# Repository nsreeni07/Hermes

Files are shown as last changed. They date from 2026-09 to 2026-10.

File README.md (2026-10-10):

# Hermes
A 1.7m dual-deployment rocket for both L1 and L2 certification flights, with two redundant flight computers each able to trigger deployment independently. The custom Polaris board also logs data and GPS, with LoRa telemetry in progress for live ground tracking.

I made this project as part of my L1 and L2 certifications and to build my knowledge in rocketry and electronics!

Onshape: https://cad.onshape.com/documents/f1774f8f284ac4e0e452cbcf/w/6986ab179f432bdf2c956942/e/921751107e9de1a38870b9fc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









|Category |Name |Price  |Source |Purpose |FIELD6|Quantity|
|---|---|---|---|---|---|---|
|Electronics |JLC PCB |$250.00|JLCPCB | | | |
| |Header Pins |$0.90  |https://tinyurl.com/3wcsp2uy | | |1 |
| |Screw Terminals |$0.00  |Already Have | | |1 |
| |JST Connector |$0.00  |Already Have | | |1 |
| |Eggtimer Quantum|$40.00 |https://eggtimerrocketry.com/home/altimeters-av-bay/ |Dual Depolyement Controller | |1 |
| |30AWG Wire |$7.76  |https://www.aliexpress.com/item/3256808061834409.html |Wire | |1 |
| |24AWG Wire |$3.14  |https://www.aliexpress.us/item/3256806193213283.html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 |Wire | |1 |
| |Ipex to SMA |$1.50  |https://www.aliexpress.us/item/3256804886872801.html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 |Converter | |1 |
| |915mhz Antenna  |$3.79  |https://www.aliexpress.us/item/3256806722102680.html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 |Antenna | |1 |
| |SK6812 Mini |$4.87  |https://www.aliexpress.us/item/3256810305129996.html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 |SMD Led | |1 |
| |Lipo Battery |$11.52 |https://www.aliexpress.us/item/3256805071060352.html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 |Battery for Flight Computers | |2 |
| | | | | | | |
| | | | | | | |
| | | | | | | |
|Category |Name |Price  |Source |Purpose | |Quantity|
|Hardware |4.00in Body Tube|$35.54 |https://locprecision.com/products/cardboard-airframes?variant=39778656157887 |Main Airframe | |2 |
| |Coupler Tube |$8.02  |https://locprecision.com/products/tube-coupler?variant=39778656583871 |Coupler Tube/Avionics Bay | |1 |
| |Engine Block |$6.18  |https://locprecision.com/products/motor-mount-tubing?variant=39778657075391 |Engine Block | |1 |
| |1/4 U-Bolt |$13.29 |https://locprecision.com/products/eye-bolt-set?variant=39778646655167 |U Bolt for Avionics and Nose Cone | |3 |
| |3/8 U-Bolt |$6.00  |https://locprecision.com/products/eye-bolt-set?variant=48207573090537 |U Bolt on Fin Can | |1 |
| |M8 Threaded Rods|$6.93  |https://tinyurl.com/3h6k9hsu |Threaded Rods for avionics bay | |2 |
| |M8 Nuts |$6.04  |https://tinyurl.com/4r9wnyaz |Nuts For Threaded Rods | |12 |
| |M2 Shear Pins |$1.62  |https://www.aliexpress.us/item/3256807139253673.html |Shear Pins | |1 |
| |Quick Links |$10.24 |https://tinyurl.com/3hvfnt9b |Quick Link to attach Parachute Lines | |4 |
| |Wago Connectors |$7.14  |aliexpress.us/item/3256809908420918.html?spm=a2g0o.detail.0.0.8c9b0XkI0XkIkc&mp=1&pdp_npi=6%40dis%21USD%21USD%205.86%21USD%205.45%21%21USD%205.45%21%21%21%402101e81117910640636947235e108f%2112000051124972590%21ct%21US%217130607314%21%211%210%21&_gl=1*wfkgu*_gcl_aw*R0NMLjE3ODYxMTc4MjQuQ2p3S0NBandoTmJUQmhCNEVpd0FzRlNnLXU4TFZRa21sZGE5cGk3aHQyejVjMHJrUVI4UnJUY3dFTmhpRVdIU0hXblBubURITTR2SnpCb0NMRE1RQXZEX0J3RQ..*_gcl_dc*R0NMLjE3ODYxMTc4MjQuQ2p3S0NBandoTmJUQmhCNEVpd0FzRlNnLXU4TFZRa21sZGE5cGk3aHQyejVjMHJrUVI4UnJUY3dFTmhpRVdIU0hXblBubURITTR2SnpCb0NMRE1RQXZEX0J3RQ..*_gcl_au*MTM0NjA1MDQ1MS4xNzg2MTE3ODI0*_ga*MTg4NzQzODQ3Mi4xNzg2MTE3ODM1*_ga_VED1YSGNC7*czE3OTEwNjQwNjMkbzQkZzAkdDE3OTEwNjQwNjMkajYwJGwwJGgw&gatewayAdapt=glo2usa&_randl_shipto=US |Wago to connect pyros | |1 |
| |Drogue Parachute|$7.85  |https://www.apogeerockets.com/index.php?main_page=product_supplies_info&cPath=42_309_274&products_id=2281 |Drogue released at apogee | |1 |
| |Main Parachute  |$33.08 |https://www.apogeerockets.com/index.php?main_page=product_supplies_info&products_id=2476&cPath=42_309_275 |Main Parachute to Slow Descent around 200m| |1 |
| |Nomex Blankets  |$19.32 |https://www.apogeerockets.com/Building-Supplies/Parachute-Protection/Cloth/Apogee-12in-Parachute-Protector |Protects Parachutes | |2 |
| |Shock Cord |$45.40 |https://locprecision.com/collections/model-rocket-recovery/products/shock-cords?variant=39778657665215 |Holds Parachute and Airframe together | |2 |
| |Epoxy |$7.41  |https://www.aliexpress.us/item/3256807290234101.html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|Epoxy | |1 |
| |Motor Retainer  |$6.72  |https://locprecision.com/products/z-clip-style-motor-retainer-set?_pos=1&_sid=3f87ff719&_ss=r |Motor Retainer | |1 |
| |Balsa Wood |$0.00  |Already Have |Fins and | | |
| | | | | | | |
| | | | | | | |
|Final+Tax+Shipping| | | | | | |
| | | | | | | |
|LOC |$140.00 | | | | | |
|Apogee |$80.00 | | | | | |
|Aliexpress |$78.00 | | | | | |
|Egg Timer |$50.00 | | | | | |
|JLCPCB |$250.00 | | | | | |
| | | | | | | |
| |$598.00 | | | | | |

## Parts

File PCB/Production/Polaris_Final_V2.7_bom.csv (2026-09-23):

Designator | Footprint | Quantity | Value | LCSC Part #
BUZZER1 | BUZ-SMD_4P-L7.5-W7.5-P7.59-TL | 1 | MLT-7525 | C95299
C1 | 0805 | 1 | 2.2 uf
C10, C11, C3, C4, C9 | 0805 | 5 | 22uF
C12 | 0603 | 1 | 2.7nF
C13 | 0603 | 1 | 33pF
C14, C15, C16, C17, C20, C21, C22, C23, C24, C25, C26, C31, C32 | 0402 | 13 | 100nF
C18 | 0402 | 1 | 0.1uF
C19 | 0402 | 1 | 10uF
C2, C7 | 0603 | 2 | 100nF
C27 | 0402 | 1 | 10pF
C28, C29 | 0402 | 2 | 2.2uF
C30, C33 | 0402 | 2 | 1uF
C34 | 0402 | 1 | 22nF
C36 | 0402 | 1 | 4.7uF
C37, C38, C39, C40 | 0402 | 4 | 20pF
C5 | 0805 | 1 | 10uF
C6 | 0805 | 1 | 10nF
C8 | 0805 | 1 | 47pF
CARD1 | TF-SMD_TF-01A | 1 | TF-01A | C91145
CN1 | COMM-SMD_18P-L10.1-W9.7-P1.1-TL_L76-LB | 1 | ATGM336H-6N-74 | C5804601
D1, D2 | LED_SK6812MINI_PLCC4_3.5x3.5mm_P1.75mm | 2 | SK6812MINI
D10, D3, D6, D7, D8, D9 | 0402 | 6 | LED | C25503345
D11 | 0402 | 1 | LED | C130723
D4 | 0402 | 1 | LED | C21260817
D5 | 0603 | 1 | LED | C22371297
J1 | PinHeader_1x03_P2.54mm_Vertical | 1 | Conn_01x03_Pin
J2 | PinHeader_1x04_P2.54mm_Vertical | 1 | Conn_01x04_Pin
J3, J4 | PinHeader_1x02_P2.54mm_Vertical | 2 | Conn_01x02_Pin
J5, J6 | JST_XH_B2B-XH-AM_1x02_P2.50mm_Vertical | 2 | Conn_01x02_Pin | C158012
J7 | PinHeader_1x05_P2.54mm_Vertical | 1 | Conn_01x05_Pin
J8 | JST_XH_B4B-XH-AM_1x04_P2.50mm_Vertical | 1 | Conn_01x04_Pin
L1 | L_Bourns_SRP5030T | 1 | 5.6uH | C46595886
L2 | L_Cenker_CKCS8040 | 1 | 3.6uH | C223037
L3 | 0603 | 1 | 47nH | C98076
L4 | L0603 | 1 | FCM1608KF-601T03 | C141723
M1, M2, M3, M4, M5, M6 | PinHeader_1x03_P2.54mm_Vertical | 6 | Motor_Servo
P1, P2, P3, P4, P5, P6, P7, P8 | CONN-TH_2P-P5.00_WJ500V-5.08-2P | 8 | WJ500V-5.08-2P-14-00A | C8465
Q1, Q2, Q3 | POWER-1212-8_L3.3-W3.3-P0.66-LS3.3-BL | 3 | SI7232DN-T1-GE3 | C144854
Q7 | SOT-89-3_L4.5-W2.4-P1.50-LS4.0-BR | 1 | 2N2222AU | C21714170
R1, R2 | 0402 | 2 | 5.1K
R10, R11, R12, R13, R14, R19, R30, R31, R33, R37, R38, R40, R41, R50, R51, R8, R9 | 0402 | 17 | 10K
R15, R16, R18, R25, R26, R27, R28, R32, R34, R35, R36, R39, R42, R43 | 0402 | 14 | 1k
R17 | 0402 | 1 | 470
R20, R4, R6 | 0402 | 3 | 22.1k
R21 | 0402 | 1 | 120k
R22 | 0402 | 1 | 200K
R23 | 0402 | 1 | 40K
R24 | 0402 | 1 | 550
R29 | 0402 | 1 | 75k
R3 | 0402 | 1 | 100k
R44 | 0402 | 1 | 430
R5 | 0402 | 1 | 115k
R7 | 0402 | 1 | 15.8k
RF1 | IPEX-SMD_BWIPX-1-001E | 1 | BWIPX-1-001E | C496552
SW1, SW2 | SW-SMD_L3.9-W3.0-P4.45 | 2 | TS-1088-AR02016 | C720477
U1 | LGA-10_L2.0-W2.0-P0.50-TL_BMP580 | 1 | BMP580 | C22391138
U10, U11, U12, U13, U8, U9 | F0603 | 6 | 0438006.WRGT | C206962
U2 | LQFP-100_14x14mm_P0.5mm | 1 | STM32H743VITx | C114409
U3 | LGA-14_L3.0-W2.5-P0.50-TL | 1 | ICM-45686 | C22459454
U4 | SOT-23-6_L2.9-W1.6-P0.95-LS2.8-BL | 1 | LMR51430XDDCR | C5185863
U5 | SOIC-8_L4.9-W3.9-P1.27-LS6.0-BL-EP-1 | 1 | AP64501SP-13 | C2071517
U6 | WIRELM-SMD_RA-02-BL | 1 | RA-02 | C90039
U7 | VQFN-HR-12_L2.5-W2.0-P0.50-BL | 1 | TPS2121RUXR | C485916
USB1 | USB-C-SMD_TYPE-C16PIN | 1 | TYPE-C16PIN | C393939
X1 | CRYSTAL-SMD_4P-L3.2-W2.5-BL | 1 | X322525MOB4SI | C9006
X2 | FC-135R_L3.2-W1.5 | 1 | Q13FC1350000400 | C32346

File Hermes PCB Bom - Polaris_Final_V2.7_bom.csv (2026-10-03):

Designator | Footprint | Quantity | Value | LCSC Part # | Link
BUZZER1 | BUZ-SMD_4P-L7.5-W7.5-P7.59-TL | 1 | MLT-7525 | C95299 | https://www.lcsc.com/product-detail/C95299.html?s_z=n_q_C95299&globalKeyword=C95299
C1 | 805 | 1 | 2.2 uf |  | https://www.lcsc.com/product-detail/C23630.html?s_z=n_q_t_2.2%2520uf
C10, C11, C3, C4, C9 | 805 | 5 | 22uF |  | https://www.lcsc.com/product-detail/C59461.html?s_z=n_q_t_22uF
C12 | 603 | 1 | 2.7nF |  | https://www.lcsc.com/product-detail/C106251.html?s_z=n_q_t_2.7nF
C13 | 603 | 1 | 33pF |  | https://www.lcsc.com/product-detail/C1663.html?s_z=n_q_t_33pF
C14, C15, C16, C17, C20, C21, C22, C23, C24, C25, C26, C31, C32 | 402 | 13 | 100nF |  | https://www.lcsc.com/product-detail/C14663.html?s_z=n_q_t_100nF
C18 | 402 | 1 | 0.1uF |  | https://www.lcsc.com/product-detail/C14663.html?s_z=n_q_t_0.1uF
C19 | 402 | 1 | 10uF |  | https://www.lcsc.com/product-detail/C19702.html?s_z=n_q_t_10uF
C2, C7 | 603 | 2 | 100nF |  | https://www.lcsc.com/product-detail/C14663.html?s_z=n_q_t_100nF
C27 | 402 | 1 | 10pF |  | https://www.lcsc.com/product-detail/C1634.html?s_z=n_q_t_10pF
C28, C29 | 402 | 2 | 2.2uF |  | https://www.lcsc.com/product-detail/C23630.html?s_z=n_q_t_2.2uF
C30, C33 | 402 | 2 | 1uF |  | https://www.lcsc.com/product-detail/C5199872.html?s_z=n_q_t_1uF
C34 | 402 | 1 | 22nF |  | https://www.lcsc.com/category/1142.html?scene=FULL_MATCH&globalKeyword=22nF&s_z=n_q_t_22nF
C36 | 402 | 1 | 4.7uF |  | https://www.lcsc.com/product-detail/C1705.html?s_z=n_q_t_4.7uF
C37, C38, C39, C40 | 402 | 4 | 20pF |  | https://www.lcsc.com/product-detail/C1648.html?s_z=n_q_t_20pF
C5 | 805 | 1 | 10uF |  | https://www.lcsc.com/product-detail/C19702.html?s_z=n_q_t_10uF
C6 | 805 | 1 | 10nF |  | https://www.lcsc.com/product-detail/C100042.html?s_z=n_q_t_10nF
C8 | 805 | 1 | 47pF |  | https://www.lcsc.com/product-detail/C1671.html?s_z=n_q_t_47pF
CARD1 | TF-SMD_TF-01A | 1 | TF-01A | C91145 | https://www.lcsc.com/product-detail/C91145.html?s_z=n_q_C91145&globalKeyword=C91145
CN1 | COMM-SMD_18P-L10.1-W9.7-P1.1-TL_L76-LB | 1 | ATGM336H-6N-74 | C5804601 | https://www.lcsc.com/product-detail/C5804601.html?s_z=n_q_C5804601&globalKeyword=C5804601
D1, D2 | LED_SK6812MINI_PLCC4_3.5x3.5mm_P1.75mm | 2 | SK6812MINI |  | https://www.aliexpress.us/item/3256805007401420.html?curPageLogUid=6aUNvXCADmxt
D10, D3, D6, D7, D8, D9 | 402 | 6 | LED | C25503345 | https://www.lcsc.com/product-detail/C25503345.html?s_z=n_q_C25503345&globalKeyword=C25503345
D11 | 402 | 1 | LED | C130723 | https://www.lcsc.com/product-detail/C130723.html?s_z=n_q_C130723&globalKeyword=C130723
D4 | 402 | 1 | LED | C21260817 | https://www.lcsc.com/product-detail/C21260817.html?s_z=n_q_C21260817&globalKeyword=C21260817
D5 | 603 | 1 | LED | C22371297 | https://www.lcsc.com/product-detail/C22371297.html?s_z=n_q_C22371297&globalKeyword=C22371297
J1 | PinHeader_1x03_P2.54mm_Vertical | 1 | Conn_01x03_Pin |  | https://tinyurl.com/3wcsp2uy
J2 | PinHeader_1x04_P2.54mm_Vertical | 1 | Conn_01x04_Pin |  | https://tinyurl.com/3wcsp2uy
J3, J4 | PinHeader_1x02_P2.54mm_Vertical | 2 | Conn_01x02_Pin |  | https://tinyurl.com/3wcsp2uy
J5, J6 | JST_XH_B2B-XH-AM_1x02_P2.50mm_Vertical | 2 | Conn_01x02_Pin | C158012 | Already Have
J7 | PinHeader_1x05_P2.54mm_Vertical | 1 | Conn_01x05_Pin |  | https://tinyurl.com/3wcsp2uy
J8 | JST_XH_B4B-XH-AM_1x04_P2.50mm_Vertical | 1 | Conn_01x04_Pin |  | Already Have
L1 | L_Bourns_SRP5030T | 1 | 5.6uH | C46595886 | https://www.lcsc.com/product-detail/C46595886.html?s_z=n_q_C46595886&globalKeyword=C46595886
L2 | L_Cenker_CKCS8040 | 1 | 3.6uH | C223037 | https://www.lcsc.com/product-detail/C223037.html?s_z=n_q_C223037&globalKeyword=C223037
L3 | 603 | 1 | 47nH | C98076 | https://www.lcsc.com/product-detail/C98076.html?s_z=n_q_C98076&globalKeyword=C98076
L4 | L0603 | 1 | FCM1608KF-601T03 | C141723 | https://www.lcsc.com/product-detail/C141723.html?s_z=n_q_C141723&globalKeyword=C141723
M1, M2, M3, M4, M5, M6 | PinHeader_1x03_P2.54mm_Vertical | 6 | Motor_Servo |  | https://tinyurl.com/3wcsp2uy
P1, P2, P3, P4, P5, P6, P7, P8 | CONN-TH_2P-P5.00_WJ500V-5.08-2P | 8 | WJ500V-5.08-2P-14-00A | C8465 | Already have
Q1, Q2, Q3 | POWER-1212-8_L3.3-W3.3-P0.66-LS3.3-BL | 3 | SI7232DN-T1-GE3 | C144854 | https://www.lcsc.com/product-detail/C144854.html?s_z=n_q_C144854&globalKeyword=C144854
Q7 | SOT-89-3_L4.5-W2.4-P1.50-LS4.0-BR | 1 | 2N2222AU | C21714170 | https://www.lcsc.com/product-detail/C21714170.html?s_z=n_q_C21714170&globalKeyword=C21714170
R1, R2 | 402 | 2 | 5.1K |  | https://www.lcsc.com/product-detail/C2907044.html?s_z=n_q_t_5.1K
R10, R11, R12, R13, R14, R19, R30, R31, R33, R37, R38, R40, R41, R50, R51, R8, R9 | 402 | 17 | 10K |  | https://www.lcsc.com/product-detail/C98220.html?s_z=n_q_t_10K
R15, R16, R18, R25, R26, R27, R28, R32, R34, R35, R36, R39, R42, R43 | 402 | 14 | 1k |  | https://www.lcsc.com/product-detail/C22548.html?s_z=n_q_t_1k
R17 | 402 | 1 | 470 |  | https://www.lcsc.com/product-detail/C2909361.html?s_z=s_q_t_470%25CE%25A9%25200402
R20, R4, R6 | 402 | 3 | 22.1k |  | https://www.lcsc.com/product-detail/C2960862.html?s_z=n_q_t_22.1k
R21 | 402 | 1 | 120k |  | https://www.lcsc.com/product-detail/C25808.html?s_z=n_q_t_120k%27
R22 | 402 | 1 | 200K |  | https://www.lcsc.com/product-detail/C17954.html?s_z=n_q_t_200K
R23 | 402 | 1 | 40K |  | https://www.lcsc.com/product-detail/C861392.html?s_z=n_q_t_40K
R24 | 402 | 1 | 550 |  | https://www.lcsc.com/product-detail/C2912642.html?s_z=n_q_t_550%2520resistor
R29 | 402 | 1 | 75k |  | https://www.lcsc.com/product-detail/C2933753.html?s_z=n_q_t_75k
R3 | 402 | 1 | 100k |  | https://www.lcsc.com/product-detail/C14675.html?s_z=n_q_t_100k
R44 | 402 | 1 | 430 |  | https://www.lcsc.com/product-detail/C2907036.html?s_z=n_q_t_430%2520resistor
R5 | 402 | 1 | 115k |  | https://www.lcsc.com/product-detail/C273341.html?s_z=n_q_t_115k
R7 | 402 | 1 | 15.8k |  | https://www.lcsc.com/product-detail/C861143.html?s_z=n_q_t_15.8k
RF1 | IPEX-SMD_BWIPX-1-001E | 1 | BWIPX-1-001E | C496552 | https://www.lcsc.com/product-detail/C496552.html?s_z=n_q_C496552&globalKeyword=C496552
SW1, SW2 | SW-SMD_L3.9-W3.0-P4.45 | 2 | TS-1088-AR02016 | C720477 | https://www.lcsc.com/product-detail/C720477.html?s_z=n_q_C720477&globalKeyword=C720477
U1 | LGA-10_L2.0-W2.0-P0.50-TL_BMP580 | 1 | BMP580 | C22391138 | https://www.lcsc.com/product-detail/C22391138.html?s_z=n_q_C22391138&globalKeyword=C22391138
U10, U11, U12, U13, U8, U9 | F0603 | 6 | 0438006.WRGT | C206962 | https://www.lcsc.com/product-detail/C206962.html?s_z=n_q_C206962&globalKeyword=C206962
U2 | LQFP-100_14x14mm_P0.5mm | 1 | STM32H743VITx | C114409 | https://www.lcsc.com/product-detail/C114409.html?s_z=n_q_C114409&globalKeyword=C114409
U3 | LGA-14_L3.0-W2.5-P0.50-TL | 1 | ICM-45686 | C22459454 | https://www.lcsc.com/product-detail/C22459454.html?s_z=n_q_C22459454&globalKeyword=C22459454
U4 | SOT-23-6_L2.9-W1.6-P0.95-LS2.8-BL | 1 | LMR51430XDDCR | C5185863 | https://www.lcsc.com/product-detail/C5185863.html?s_z=n_q_C5185863&globalKeyword=C5185863
U5 | SOIC-8_L4.9-W3.9-P1.27-LS6.0-BL-EP-1 | 1 | AP64501SP-13 | C2071517 | https://www.lcsc.com/product-detail/C2071517.html?s_z=n_q_C2071517&globalKeyword=C2071517
U6 | WIRELM-SMD_RA-02-BL | 1 | RA-02 | C90039 | https://www.lcsc.com/product-detail/C90039.html?s_z=n_q_C90039&globalKeyword=C90039
U7 | VQFN-HR-12_L2.5-W2.0-P0.50-BL | 1 | TPS2121RUXR | C485916 | https://www.lcsc.com/product-detail/C485916.html?s_z=n_q_C485916&globalKeyword=C485916
USB1 | USB-C-SMD_TYPE-C16PIN | 1 | TYPE-C16PIN | C393939 | https://www.lcsc.com/product-detail/C393939.html?s_z=n_q_C393939&globalKeyword=C393939
X1 | CRYSTAL-SMD_4P-L3.2-W2.5-BL | 1 | X322525MOB4SI | C9006 | https://www.lcsc.com/product-detail/C9006.html?s_z=n_q_C9006&globalKeyword=C9006
X2 | FC-135R_L3.2-W1.5 | 1 | Q13FC1350000400 | C32346 | https://www.lcsc.com/product-detail/C32346.html?s_z=n_q_C32346&globalKeyword=C32346

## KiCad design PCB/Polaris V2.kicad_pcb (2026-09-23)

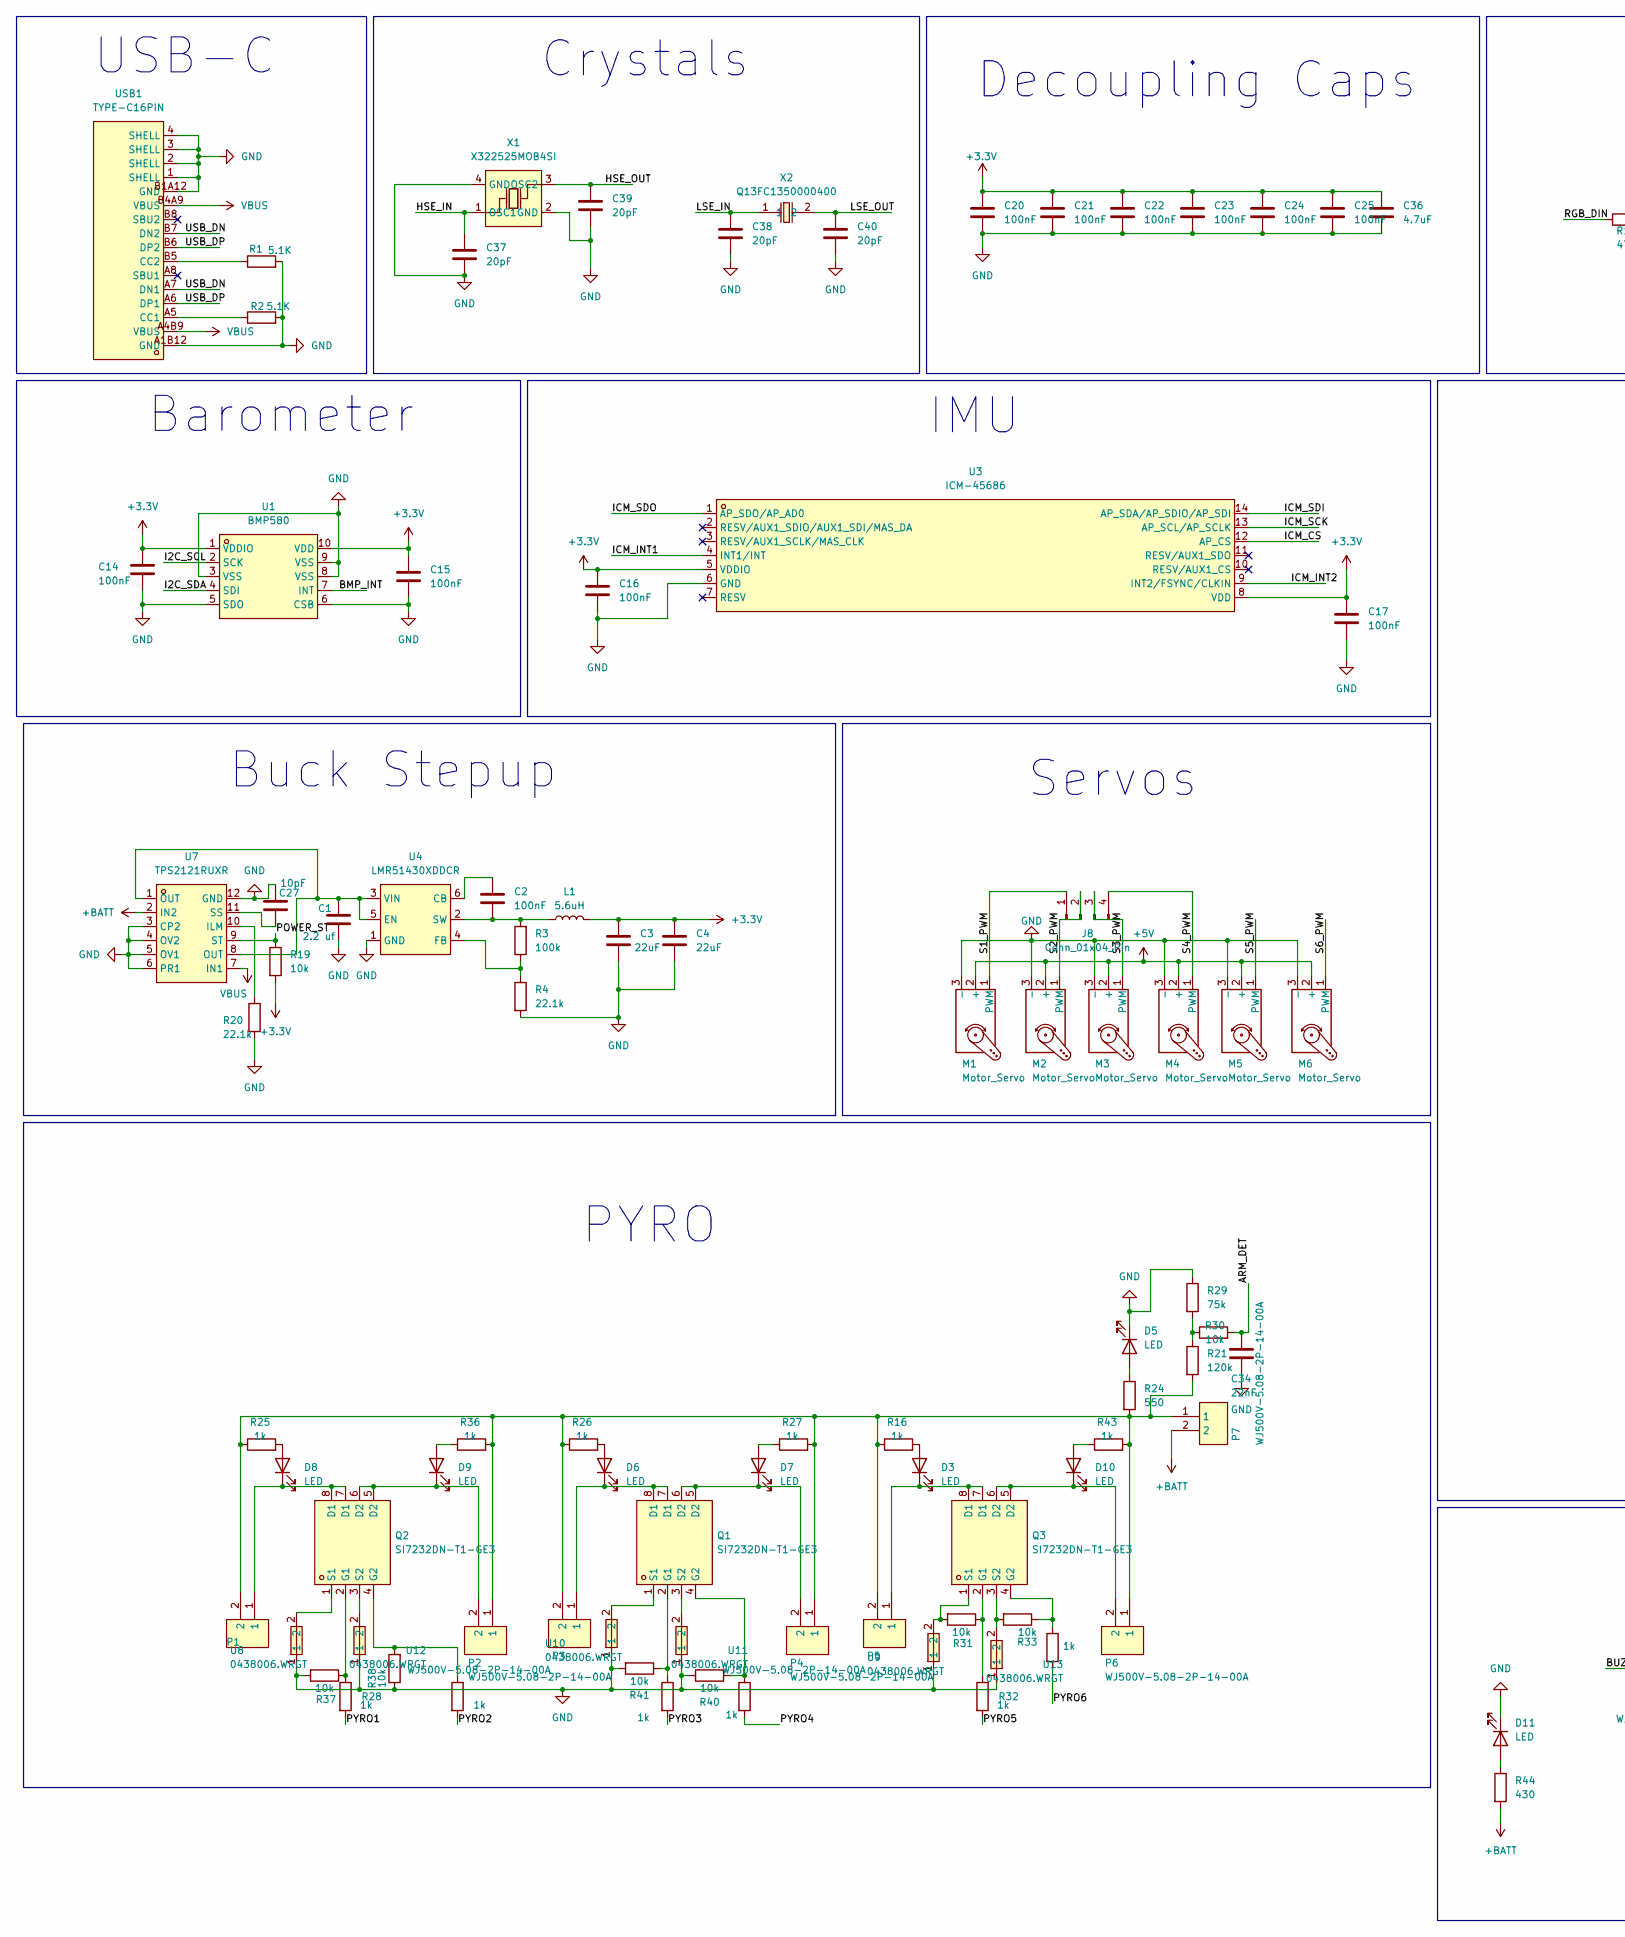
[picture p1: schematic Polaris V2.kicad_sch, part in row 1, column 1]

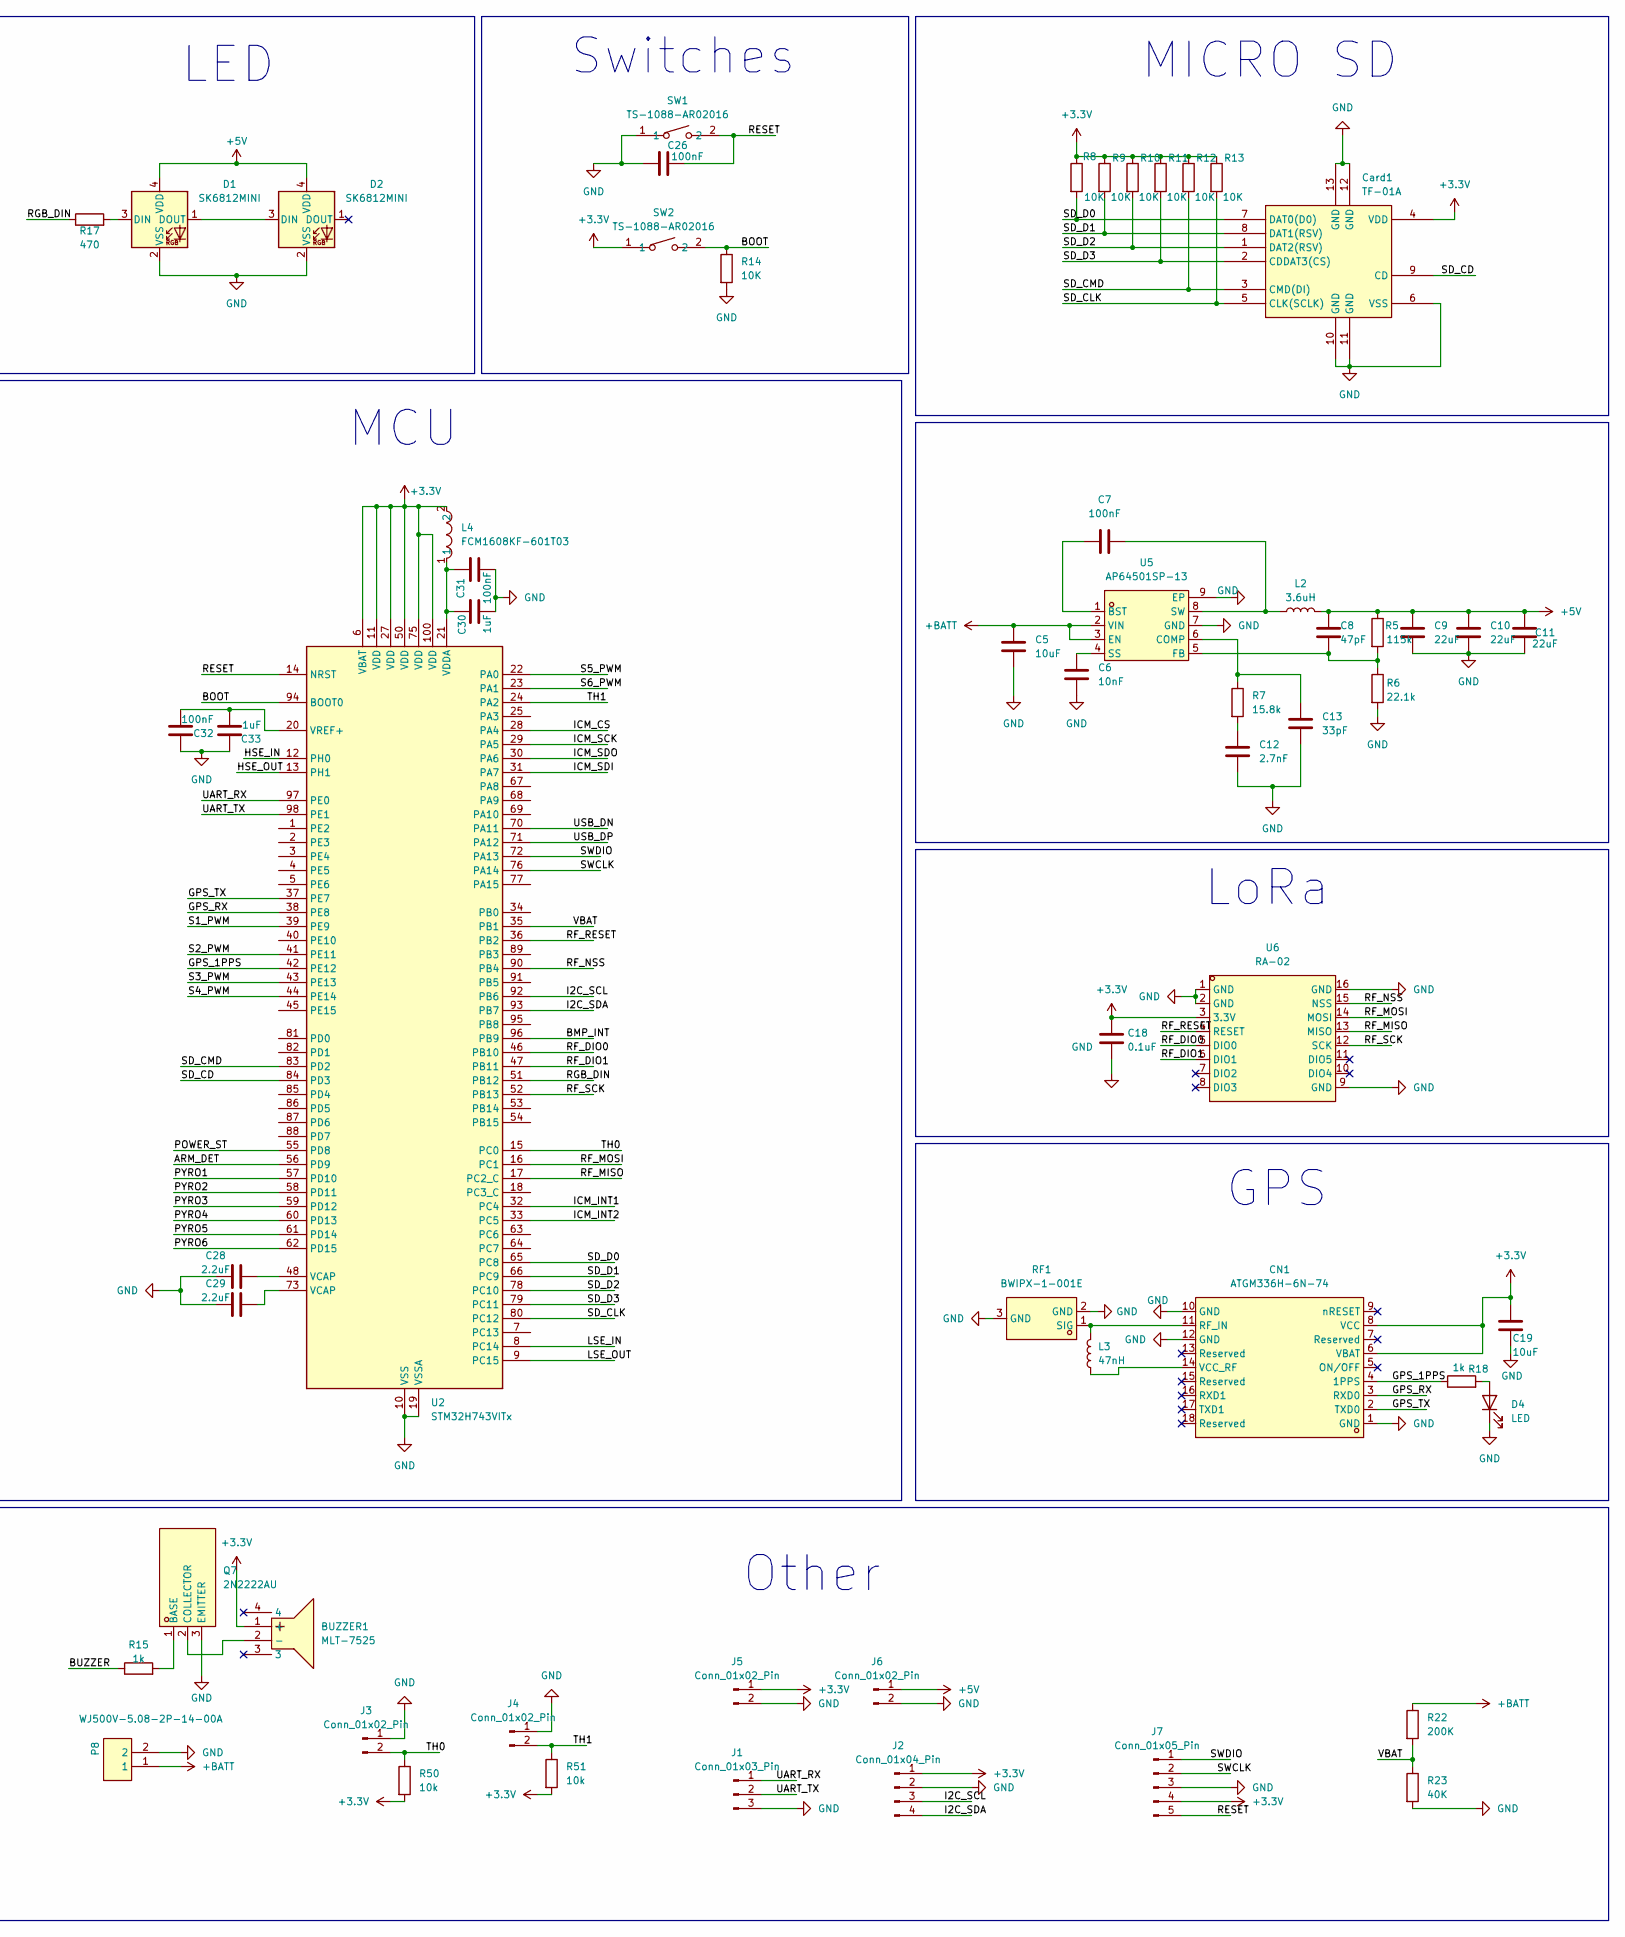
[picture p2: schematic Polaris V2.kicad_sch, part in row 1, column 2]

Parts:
BUZZER1: MLT-7525; BUZ-SMD_4P-L7.5-W7.5-P7.59-TL; LCSC Part C95299
C1: 2.2 uf; C_0805_2012Metric
C2, C7: 100nF; C_0603_1608Metric
C3, C4, C9, C10, C11: 22uF; C_0805_2012Metric
C5: 10uF; C_0805_2012Metric
C6: 10nF; C_0805_2012Metric
C8: 47pF; C_0805_2012Metric
C12: 2.7nF; C_0603_1608Metric
C13: 33pF; C_0603_1608Metric
C14, C15, C16, C17, C20, C21, C22, C23, C24, C25, C26, C31, C32: 100nF; C_0402_1005Metric
C18: 0.1uF; C_0402_1005Metric
C19: 10uF; C_0402_1005Metric
C27: 10pF; C_0402_1005Metric
C28, C29: 2.2uF; C_0402_1005Metric
C30, C33: 1uF; C_0402_1005Metric
C34: 22nF; C_0402_1005Metric
C36: 4.7uF; C_0402_1005Metric
C37, C38, C39, C40: 20pF; C_0402_1005Metric
CN1: ATGM336H-6N-74; COMM-SMD_18P-L10.1-W9.7-P1.1-TL_L76-LB; LCSC Part C5804601
Card1: TF-01A; TF-SMD_TF-01A; LCSC Part C91145
D1, D2: SK6812MINI; LED_SK6812MINI_PLCC4_3.5x3.5mm_P1.75mm
D3, D4, D6, D7, D8, D9, D10: LED; LED_0402_1005Metric
D5: LED; LED_0603_1608Metric
D11: LED; LED_0402_1005Metric; LCSC C130723
J1: Conn_01x03_Pin; PinHeader_1x03_P2.54mm_Vertical
J2: Conn_01x04_Pin; PinHeader_1x04_P2.54mm_Vertical
J3, J4: Conn_01x02_Pin; PinHeader_1x02_P2.54mm_Vertical
J5, J6: Conn_01x02_Pin; JST_XH_B2B-XH-AM_1x02_P2.50mm_Vertical; LCSC C158012
J7: Conn_01x05_Pin; PinHeader_1x05_P2.54mm_Vertical
J8: Conn_01x04_Pin; JST_XH_B4B-XH-AM_1x04_P2.50mm_Vertical
L1: 5.6uH; L_Bourns_SRP5030T; LCSC C46595886
L2: 3.6uH; L_Cenker_CKCS8040; LCSC C223037
L3: 47nH; L_0603_1608Metric_Pad1.05x0.95mm_HandSolder; LCSC C98076
L4: FCM1608KF-601T03; L0603; LCSC Part C141723
M1, M2, M3, M4, M5, M6: Motor_Servo; PinHeader_1x03_P2.54mm_Vertical
P1, P2, P3, P4, P5, P6, P7, P8: WJ500V-5.08-2P-14-00A; CONN-TH_2P-P5.00_WJ500V-5.08-2P; LCSC Part C8465
Q1, Q2, Q3: SI7232DN-T1-GE3; POWER-1212-8_L3.3-W3.3-P0.66-LS3.3-BL; LCSC Part C144854
Q7: 2N2222AU; SOT-89-3_L4.5-W2.4-P1.50-LS4.0-BR; LCSC Part C21714170
R1, R2: 5.1K; R_0402_1005Metric
R3: 100k; R_0402_1005Metric
R4, R6, R20: 22.1k; R_0402_1005Metric
R5: 115k; R_0402_1005Metric
R7: 15.8k; R_0402_1005Metric
R8, R9, R10, R11, R12, R13, R14: 10K; R_0402_1005Metric
R15, R16, R18, R25, R26, R27, R28, R32, R34, R35, R36, R39, R42, R43: 1k; R_0402_1005Metric
R17: 470; R_0402_1005Metric
R19, R30, R31, R33, R37, R38, R40, R41, R50, R51: 10k; R_0402_1005Metric
R21: 120k; R_0402_1005Metric
R22: 200K; R_0402_1005Metric
R23: 40K; R_0402_1005Metric
R24: 550; R_0402_1005Metric
R29: 75k; R_0402_1005Metric
R44: 430; R_0402_1005Metric
RF1: BWIPX-1-001E; IPEX-SMD_BWIPX-1-001E; LCSC Part C496552
SW1, SW2: TS-1088-AR02016; SW-SMD_L3.9-W3.0-P4.45; LCSC Part C720477
U1: BMP580; LGA-10_L2.0-W2.0-P0.50-TL_BMP580; LCSC Part C22391138
U2: STM32H743VITx; LQFP-100_14x14mm_P0.5mm
U3: ICM-45686; LGA-14_L3.0-W2.5-P0.50-TL; LCSC Part C22459454
U4: LMR51430XDDCR; SOT-23-6_L2.9-W1.6-P0.95-LS2.8-BL; LCSC Part C5185863
U5: AP64501SP-13; SOIC-8_L4.9-W3.9-P1.27-LS6.0-BL-EP-1; LCSC Part C2071517
U6: RA-02; WIRELM-SMD_RA-02-BL; LCSC Part C90039
U7: TPS2121RUXR; VQFN-HR-12_L2.5-W2.0-P0.50-BL; LCSC Part C485916
U8, U9, U10, U11, U12, U13: 0438006.WRGT; F0603; LCSC Part C206962
USB1: TYPE-C16PIN; USB-C-SMD_TYPE-C16PIN; LCSC Part C393939
X1: X322525MOB4SI; CRYSTAL-SMD_4P-L3.2-W2.5-BL; LCSC Part C9006
X2: Q13FC1350000400; FC-135R_L3.2-W1.5; LCSC Part C32346

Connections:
+3.3V: BUZZER1.1 (+), C3.1, C4.1, C14.1, C15.1, C16.1, C17.1, C18.1, C19.1, C20.1, C21.1, C22.1, C23.1, C24.1, C25.1, C36.1, CN1.6 (VBAT), CN1.8 (VCC), Card1.4 (VDD), J2.1, J5.1, J7.4, L1.2, L4.2, R8.1, R9.1, R10.1, R11.1, R12.1, R13.1, R19.2, R50.2, R51.2, SW2.1, U1.1 (VDDIO), U1.10 (VDD), U2.6 (VBAT), U2.11 (VDD), U2.27 (VDD), U2.50 (VDD), U2.75 (VDD), U2.100 (VDD), U3.5 (VDDIO), U3.8 (VDD), U6.3 (3.3V)
+5V: C8.1, C9.1, C10.1, C11.1, D1.4 (VDD), D2.4 (VDD), J6.1, L2.2, M1.2 (+), M2.2 (+), M3.2 (+), M4.2 (+), M5.2 (+), M6.2 (+), R5.1
+BATT: C5.1, P7.2, P8.1, R22.1, R44.2, U5.2 (VIN), U5.3 (EN), U7.2 (IN2)
/ARM_DET: C34.1, R30.2, U2.56 (PD9)
/BMP_INT: U1.7 (INT), U2.96 (PB9)
/BOOT: R14.1, SW2.2, U2.94 (BOOT0)
/BUZZER: R15.1, U2.53 (PB14)
/GPS_1PPS: CN1.4 (1PPS), R18.1, U2.42 (PE12)
/GPS_RX: CN1.3 (RXD0), U2.38 (PE8)
/GPS_TX: CN1.2 (TXD0), U2.37 (PE7)
/HSE_IN: C37.1, U2.12 (PH0), X1.1 (OSC1)
/HSE_OUT: C39.1, U2.13 (PH1), X1.3 (OSC2)
/I2C_SCL: J2.3, U1.2 (SCK), U2.92 (PB6)
/I2C_SDA: J2.4, U1.4 (SDI), U2.93 (PB7)
/ICM_CS: U2.28 (PA4), U3.12 (AP_CS)
/ICM_INT1: U2.32 (PC4), U3.4 (INT1/INT)
/ICM_INT2: U2.33 (PC5), U3.9 (INT2/FSYNC/CLKIN)
/ICM_SCK: U2.29 (PA5), U3.13 (AP_SCL/AP_SCLK)
/ICM_SDI: U2.31 (PA7), U3.14 (AP_SDA/AP_SDIO/AP_SDI)
/ICM_SDO: U2.30 (PA6), U3.1 (AP_SDO/AP_AD0)
/LSE_IN: C38.1, U2.8 (PC14), X2.1
/LSE_OUT: C40.1, U2.9 (PC15), X2.2
/POWER_ST: R19.1, U2.55 (PD8), U7.9 (ST)
/PYRO1: R28.2, U2.57 (PD10)
/PYRO2: R34.2, U2.58 (PD11)
/PYRO3: R35.2, U2.59 (PD12)
/PYRO4: R39.2, U2.60 (PD13)
/PYRO5: R32.2, U2.61 (PD14)
/PYRO6: R42.2, U2.62 (PD15)
/RESET: C26.2, J7.5, SW1.2, U2.14 (NRST)
/RF_DIO0: U2.46 (PB10), U6.5 (DIO0)
/RF_DIO1: U2.47 (PB11), U6.6 (DIO1)
/RF_MISO: U2.17 (PC2_C), U6.13 (MISO)
/RF_MOSI: U2.16 (PC1), U6.14 (MOSI)
/RF_NSS: U2.90 (PB4), U6.15 (NSS)
/RF_RESET: U2.36 (PB2), U6.4 (RESET)
/RF_SCK: U2.52 (PB13), U6.12 (SCK)
/RGB_DIN: R17.1, U2.51 (PB12)
/S1_PWM: J8.1, M1.1 (PWM), U2.39 (PE9)
/S2_PWM: J8.2, M2.1 (PWM), U2.41 (PE11)
/S3_PWM: J8.3, M3.1 (PWM), U2.43 (PE13)
/S4_PWM: J8.4, M4.1 (PWM), U2.44 (PE14)
/S5_PWM: M5.1 (PWM), U2.22 (PA0)
/S6_PWM: M6.1 (PWM), U2.23 (PA1)
/SD_CD: Card1.9 (CD), U2.84 (PD3)
/SD_CLK: Card1.5 (CLK(SCLK)), R13.2, U2.80 (PC12)
/SD_CMD: Card1.3 (CMD(DI)), R12.2, U2.83 (PD2)
/SD_D0: Card1.7 (DAT0(D0)), R8.2, U2.65 (PC8)
/SD_D1: Card1.8 (DAT1(RSV)), R9.2, U2.66 (PC9)
/SD_D2: Card1.1 (DAT2(RSV)), R10.2, U2.78 (PC10)
/SD_D3: Card1.2 (CDDAT3(CS)), R11.2, U2.79 (PC11)
/SWCLK: J7.2, U2.76 (PA14)
/SWDIO: J7.1, U2.72 (PA13)
/TH0: J3.2, R50.1, U2.15 (PC0)
/TH1: J4.2, R51.1, U2.24 (PA2)
/UART_RX: J1.1, U2.97 (PE0)
/UART_TX: J1.2, U2.98 (PE1)
/USB_DN: U2.70 (PA11), USB1.A7 (DN1), USB1.B7 (DN2)
/USB_DP: U2.71 (PA12), USB1.A6 (DP1), USB1.B6 (DP2)
/VBAT: R22.2, R23.1, U2.35 (PB1)
GND: C1.2, C3.2, C4.2, C5.2, C6.2, C9.2, C10.2, C11.2, C12.2, C13.2, C14.2, C15.2, C16.2, C17.2, C18.2, C19.2, C20.2, C21.2, C22.2, C23.2, C24.2, C25.2, C26.1, C27.1, C28.1, C29.1, C30.2, C31.2, C32.1, C33.1, C34.2, C36.2, C37.2, C38.2, C39.2, C40.2, CN1.1 (GND), CN1.10 (GND), CN1.12 (GND), Card1.6 (VSS), Card1.10 (GND), Card1.11 (GND), Card1.12 (GND), Card1.13 (GND), D1.2 (VSS), D2.2 (VSS), D4.1 (K), D5.1 (K), D11.1 (K), J1.3, J2.2, J3.1, J4.1, J5.2, J6.2, J7.3, M1.3 (-), M2.3 (-), M3.3 (-), M4.3 (-), M5.3 (-), M6.3 (-), P8.2, Q7.3 (EMITTER), R1.2, R2.2, R4.2, R6.2, R14.2, R20.2, R23.2, R29.1, R37.2, R38.1, R40.1, R41.2, RF1.2 (GND), RF1.3 (GND), SW1.1, U1.3 (VSS), U1.5 (SDO), U1.6 (CSB), U1.8 (VSS), U1.9 (VSS), U2.10 (VSS), U2.19 (VSSA), U2.26 (VSS), U2.49 (VSS), U2.74 (VSS), U2.99 (VSS), U3.6 (GND), U4.1 (GND), U5.7 (GND), U5.9 (EP), U6.1 (GND), U6.2 (GND), U6.9 (GND), U6.16 (GND), U7.3 (CP2), U7.4 (OV2), U7.5 (OV1), U7.6 (PR1), U7.12 (GND), U8.1, U9.1, U10.1, U11.1, U12.1, U13.1, USB1.1 (SHELL), USB1.2 (SHELL), USB1.3 (SHELL), USB1.4 (SHELL), USB1.A1B12 (GND), USB1.B1A12 (GND), X1.2 (GND), X1.4 (GND)
unnamed: BUZZER1.2 (-), Q7.2 (COLLECTOR)
unnamed: C12.1, R7.2
unnamed: C28.2, U2.48 (VCAP)
unnamed: C29.2, U2.73 (VCAP)
unnamed: CN1.11 (RF_IN), L3.2, RF1.1 (SIG)
unnamed: CN1.14 (VCC_RF), L3.1
unnamed: D1.3 (DIN), R17.2
unnamed: D1.1 (DOUT), D2.3 (DIN)
unnamed: D3.2 (A), R16.2
unnamed: D3.1 (K), P5.1, Q3.7 (D1), Q3.8 (D1)
unnamed: D4.2 (A), R18.2
unnamed: D5.2 (A), R24.1
unnamed: D6.2 (A), R26.2
unnamed: D6.1 (K), P3.1, Q1.7 (D1), Q1.8 (D1)
unnamed: D7.2 (A), R27.1
unnamed: D7.1 (K), P4.2, Q1.5 (D2), Q1.6 (D2)
unnamed: D8.2 (A), R25.2
unnamed: D8.1 (K), P1.1, Q2.7 (D1), Q2.8 (D1)
unnamed: D9.2 (A), R36.1
unnamed: D9.1 (K), P2.2, Q2.5 (D2), Q2.6 (D2)
unnamed: D10.2 (A), R43.1
unnamed: D10.1 (K), P6.2, Q3.5 (D2), Q3.6 (D2)
unnamed: D11.2 (A), R44.1
unnamed: P1.2, P2.1, P3.2, P4.1, P5.2, P6.1, P7.1, R16.1, R21.2, R24.2, R25.1, R26.1, R27.2, R36.2, R43.2
unnamed: Q1.2 (G1), R35.1, R41.1
unnamed: Q1.4 (G2), R39.1, R40.2
unnamed: Q1.1 (S1), U10.2
unnamed: Q1.3 (S2), U11.2
unnamed: Q2.2 (G1), R28.1, R37.1
unnamed: Q2.4 (G2), R34.1, R38.2
unnamed: Q2.1 (S1), U8.2
unnamed: Q2.3 (S2), U12.2
unnamed: Q3.2 (G1), R31.1, R32.1
unnamed: Q3.4 (G2), R33.1, R42.1
unnamed: Q3.1 (S1), R31.2, U9.2
unnamed: Q3.3 (S2), R33.2, U13.2
unnamed: Q7.1 (BASE), R15.2
unnamed: R21.1, R29.2, R30.1
unnamed: C30.1, C31.1, L4.1, U2.21 (VDDA)
unnamed: C32.2, C33.2, U2.20 (VREF+)
unnamed: C2.1, U4.6 (CB)
unnamed: C1.1, U4.3 (VIN), U4.5 (EN), U7.1 (OUT), U7.8 (OUT)
unnamed: R3.1, R4.1, U4.4 (FB)
unnamed: C2.2, L1.1, R3.2, U4.2 (SW)
unnamed: C7.1, U5.1 (BST)
unnamed: C13.1, R7.1, U5.6 (COMP)
unnamed: C8.2, R5.2, R6.1, U5.5 (FB)
unnamed: C6.1, U5.4 (SS)
unnamed: C7.2, L2.1, U5.8 (SW)
unnamed: R20.1, U7.10 (ILM)
unnamed: C27.2, U7.11 (SS)
unnamed: R2.1, USB1.A5 (CC1)
unnamed: R1.1, USB1.B5 (CC2)
VBUS: U7.7 (IN1), USB1.A4B9 (VBUS), USB1.B4A9 (VBUS)

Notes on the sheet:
USB-C
Buck Stepup
IMU
MCU
MICRO SD
Barometer
Servos
GPS
Other
PYRO
LoRa
Crystals
Decoupling Caps
Switches
LED

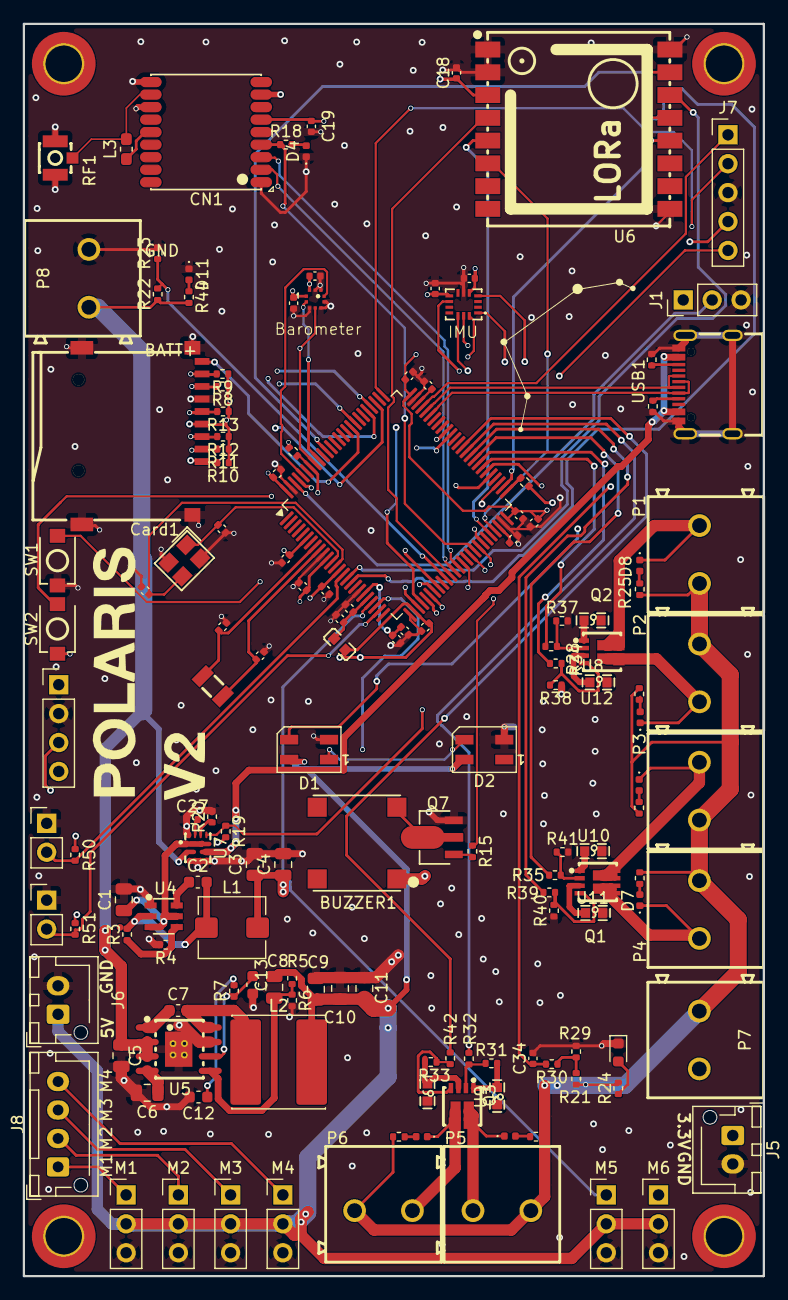
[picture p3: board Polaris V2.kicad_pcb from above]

Board: 4 copper layers, 65.0 x 110.0 mm, 148 parts (0 on the bottom side), 115 nets.

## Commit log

2026-09-22 Rename Polaris V2.kicad_pcb to PCB/Polaris V2.kicad_pcb
    [Polaris V2.kicad_pcb]
2026-09-22 Update README with Onshape link and images
    Added Onshape link for CAD documentation and included images.
2026-10-03 Rename Hermes PCB Bom - Polaris_Final_V2.7_bom.csv to BOM/Hermes PCB Bom - Polaris_Final_V2.7_bom.csv
    [Hermes PCB Bom - Polaris_Final_V2.7_bom.csv]
2026-10-16 Rename Hermes Rocket - Rail Guide.stl to CAD/Hermes Rocket - Rail Guide.stl
2026-10-16 Rename CAD/Hermes Rocket - Rail Guide.stl to CAD/STL/Hermes Rocket - Rail Guide.stl
2026-10-16 Rename CAD/Hermes Rocket - Sled.step to CAD/STEP/Hermes Rocket - Sled.step
